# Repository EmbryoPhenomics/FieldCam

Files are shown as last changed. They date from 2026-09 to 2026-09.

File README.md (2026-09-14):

# FieldCam

## A submersible field camera and sensor instrument

FieldCam is a versatile, waterproof imaging and sensing instrument, powered by consumer AA batteries and capable of long term timelapse imaging out in the field.

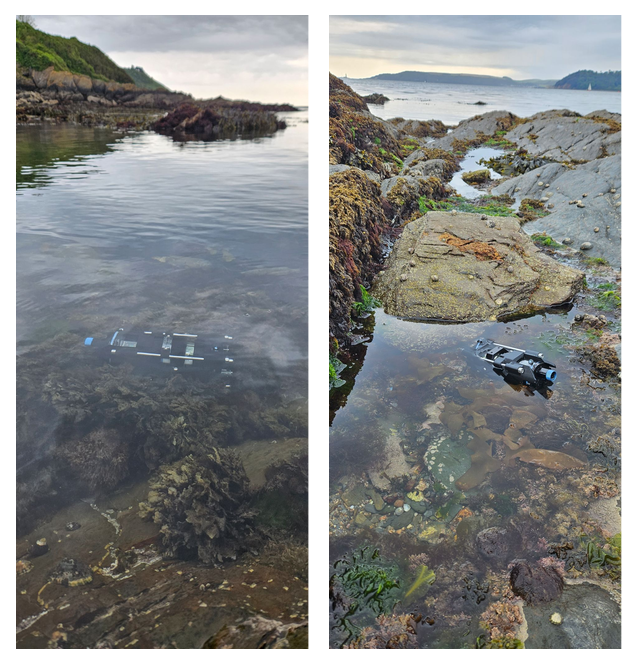
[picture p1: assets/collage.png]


 Some of the key specifications of this instrument are as follows:

| Component | Description |
|:---|:---|
| Waterproof enclosure | Acrylic tube with aluminium end caps rated to 130m depth |
| Battery | 17.1 Ah AA battery pack (~24 hrs continuous video recording). Capacity for additional 22.8 Ah AA battery pack (~30 hrs). Low power mode is > 10 years with continuous system and sensor monitoring (5 second resolution) |
| Processors | STM32 L4 microcontroller for system control and low power standby. Raspberry Pi Zero 2W for video and image capture, 32gb and 1Tb SD cards for storage respectively |
| Camera sensor | CMOS 12-megapixel (Sony IMX708) |
| Video resolution | 1080p50fps maximum. Resolution and framerate can be configured using built-in app |
| Focus | Phase Detection Autofocus (PDAF) or manual adjustable focus. Range 5cm to > 2m. | 
| Camera parameters | Exposure (Auto or manual), analogue gain and auto-white balance modes can all be configured via Web App |
| Lighting | Built-in adjustable LEDs (x2) with up to 170 lm each |
| Sensors | Temperature and light built-in. Pressure, salinity, pH and O2 available with additional sensor pack | 
| Configuration | Setup via Web App using smartphone or laptop, connected to the instrument’s wifi hotspot. Web App enables live streaming and config of camera sensor, viewing of system status and programming of experimental schedule.  All data, including video and sensor logs can be downloaded via network file sharing when in setup mode | 
| Dimensions | 70 mm x 195 mm |

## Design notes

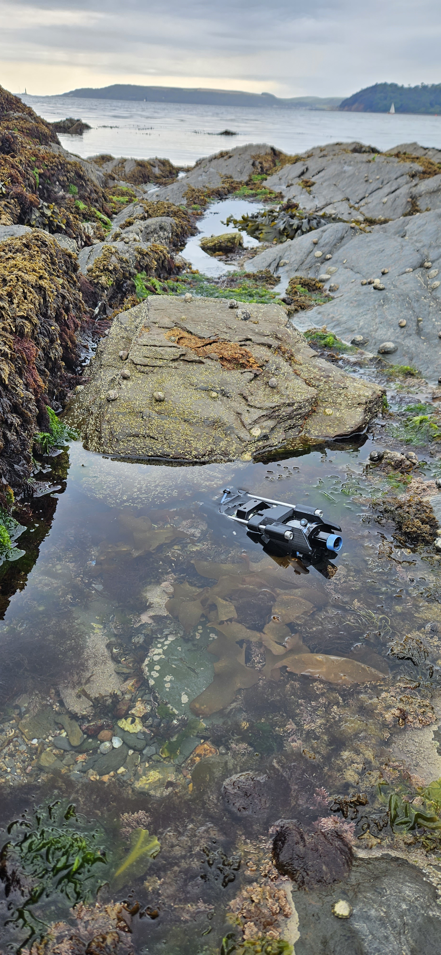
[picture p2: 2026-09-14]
assets/field_img2.jpg

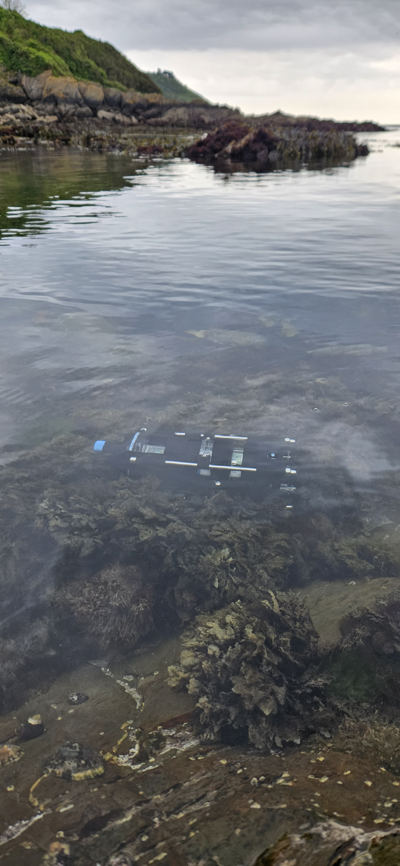
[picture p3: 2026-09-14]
assets/field_img1.jpg

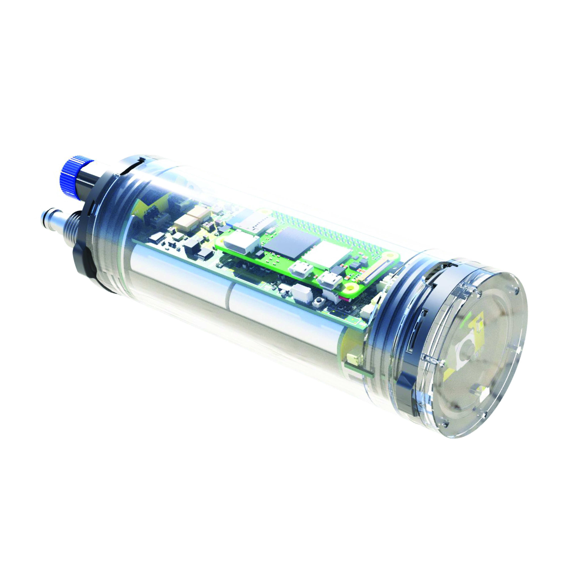
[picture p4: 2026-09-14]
assets/fieldcam_render.jpg

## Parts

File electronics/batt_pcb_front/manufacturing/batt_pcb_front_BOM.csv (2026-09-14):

Reference | Qty | Value | DNP | Exclude from BOM | Exclude from Board | Footprint | Datasheet
BT1 | 1 | Battery_Cell |  |  |  | Battery:BatteryHolder_Keystone_3000_1x12mm | ~
J1 | 1 | Conn_01x02_Socket |  |  |  | Connector_JST:JST_SH_BM02B-SRSS-TB_1x02-1MP_P1.00mm_Vertical | ~
J2,J3,J4,J5,J6,J7 | 6 | Conn_01x01_Pin |  |  |  | jlcpcb:HARWIN_S7091-42R | ~
J8 | 1 | Conn_01x02_Socket |  |  |  | Connector_JST:JST_PH_S2B-PH-SM4-TB_1x02-1MP_P2.00mm_Horizontal | ~

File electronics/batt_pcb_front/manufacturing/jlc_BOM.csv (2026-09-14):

Comment | Designator | Footprint | JLCPCB Part # | Notes | Correct?
Battery_Cell | BT1 | Battery:BatteryHolder_Keystone_3000_1x12mm | C238097 |  | Yes
Conn_01x02_Socket | J1 | Connector_JST:JST_SH_BM02B-SRSS-TB_1x02-1MP_P1.00mm_Vertical | C495537 |  | Yes
Conn_01x01_Pin | J2,J3,J4,J5,J6,J7 | jlcpcb:HARWIN_S7091-42R | C21394879 |  | Yes
Conn_01x02_Socket | J8 | Connector_JST:JST_PH_S2B-PH-SM4-TB_1x02-1MP_P2.00mm_Horizontal | C295747 |  | Yes

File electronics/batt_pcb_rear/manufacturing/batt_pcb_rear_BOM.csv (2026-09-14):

Reference | Qty | Value | DNP | Exclude from BOM | Exclude from Board | Footprint | Datasheet
H1,H2 | 2 | MountingHole |  | Excluded from BOM |  | MountingHole:MountingHole_3.2mm_M3 | ~
H3,H4 | 2 | MountingHole |  | Excluded from BOM |  | MountingHole:MountingHole_2.2mm_M2 | ~
J1,J2,J3,J4,J5,J6 | 6 | Conn_01x01_Pin |  |  |  | jlcpcb:HARWIN_S7091-42R | ~
J8 | 1 | Conn_01x04_Socket |  |  |  | Connector_JST:JST_SH_BM04B-SRSS-TB_1x04-1MP_P1.00mm_Vertical | ~
J9,J10 | 2 | Conn_01x01_Pin |  |  |  | TestPoint:TestPoint_THTPad_4.0x4.0mm_Drill2.0mm | ~
J12,J13 | 2 | Conn_01x03_Socket |  |  |  | jlcpcb:16128981 | ~

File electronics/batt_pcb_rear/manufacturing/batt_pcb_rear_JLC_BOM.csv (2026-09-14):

Comment | Designator | Footprint | JLCPCB Part # | Notes | Correct?
1uF | C1,C5 | Capacitor_SMD:C_0805_2012Metric | C77083
0.1uF | C2,C3,C6,C7 | Capacitor_SMD:C_0603_1608Metric | C77055
1000pF | C4,C8 | Capacitor_SMD:C_0402_1005Metric | C76947
10kR | R1,R2,R3,R4,R5 | Resistor_SMD:R_0603_1608Metric | C99198
TPS22997RYZR | U1,U2 | jlcpcb:WQFN-HR10_RYZ_TEX | C17286840
Conn_01x04_Socket | J8 | Connector_JST:JST_SH_BM04B-SRSS-TB_1x04-1MP_P1.00mm_Vertical | C160390

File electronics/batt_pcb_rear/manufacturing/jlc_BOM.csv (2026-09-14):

Comment | Designator | Footprint | JLCPCB Part # | Notes | Correct?
Conn_01x01_Pin | J1,J2,J3,J4,J5,J6 | jlcpcb:HARWIN_S7091-42R | C21394879
Conn_01x04_Socket | J8 | Connector_JST:JST_SH_BM04B-SRSS-TB_1x04-1MP_P1.00mm_Vertical | C495539

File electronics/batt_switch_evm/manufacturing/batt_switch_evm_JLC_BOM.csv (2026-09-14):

Comment | Designator | Footprint | JLCPCB Part # | Notes | Correct?
INA260 | U3,U1 | TSSOP-16_4.4x5mm_P0.65mm | C2155885
10kR | R3,R5,R4,R2,R1 | R_0603_1608Metric | C99198
1uF | C6 | C_0603_1608Metric | C77386
0.1uF | C4,C1,C9,C15,C12,C14,C5 | C_0603_1608Metric | C77055
100uF | C10,C8,C2 | C_1210_3225Metric | C5719639
10uF | C7,C3,C11 | C_0805_2012Metric | C84416
1000pF | C16 | C_0402_1005Metric | C76947
TPS22997RYZR | U4 | WQFN-HR10_RYZ_TEX | C17286840
1uF | C13 | C_0805_2012Metric | C77083
TPS2117 | U2 | SOT-583-8 | C22399676

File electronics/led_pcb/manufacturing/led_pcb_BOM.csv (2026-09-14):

Reference | Qty | Value | DNP | Exclude from BOM | Exclude from Board | Footprint | Datasheet
C38 | 1 | 100nF |  |  |  | Capacitor_SMD:C_0402_1005Metric | ~
D1,D2 | 2 | LED |  |  |  | jlcpcb:LED-SMD_L3.5-W2.8-R-FD-WHITE | ~
H1,H2 | 2 | MountingHole |  | Excluded from BOM |  | MountingHole:MountingHole_2.2mm_M2 | ~
J1,J2 | 2 | Conn_01x01_Socket |  |  |  | TestPoint:TestPoint_THTPad_2.0x2.0mm_Drill1.0mm | ~
J3,J4 | 2 | Conn_01x04_Socket |  |  |  | Connector_PinHeader_1.27mm:PinHeader_1x04_P1.27mm_Vertical | ~
R32 | 1 | 10kR |  |  |  | Resistor_SMD:R_0402_1005Metric | ~
U10 | 1 | VEML6030 |  |  |  | jlcpcb:VISHAY_VEML6030_2X2X0.87

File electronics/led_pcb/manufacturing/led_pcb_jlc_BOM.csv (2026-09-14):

Comment | Designator | Footprint | JLCPCB Part # | Notes | Correct?
100nF | C38 | Capacitor_SMD:C_0402_1005Metric | C1525
LED | D1,D2 | jlcpcb:LED-SMD_L3.5-W2.8-R-FD-WHITE | C2830573
10kR | R32 | Resistor_SMD:R_0402_1005Metric | C25744
VEML6030 | U10 | jlcpcb:VISHAY_VEML6030_2X2X0.87 | C132182

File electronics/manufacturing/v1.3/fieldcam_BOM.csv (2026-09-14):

Comment | Designator | Footprint | JLCPCB Part # | Notes | Correct?
4.7uF | C1,C51 | Capacitor_SMD:C_0603_1608Metric | C69335
100nF | C2,C3,C4,C7,C36,C37 | Capacitor_SMD:C_0402_1005Metric | C1525
1uF | C5,C22,C27,C33 | Capacitor_SMD:C_0603_1608Metric | C15849
10nF | C6 | Capacitor_SMD:C_0402_1005Metric | C15195
0.1uF | C8,C31 | Capacitor_SMD:C_0402_1005Metric | C307331
10uF | C9 | Capacitor_SMD:C_0603_1608Metric | C19702
15pF | C10,C11 | Capacitor_SMD:C_0402_1005Metric | C441742
0.1uF | C12,C15,C16,C19,C20,C24,C26,C30,C35,C47,C52,C53 | Capacitor_SMD:C_0603_1608Metric | C1591
22uF | C13 | Capacitor_SMD:C_0805_2012Metric | C45783
10uF | C14,C18,C21,C28,C34 | Capacitor_SMD:C_0805_2012Metric | C15850
100uF | C17,C29,C32 | Capacitor_SMD:C_1210_3225Metric | C5719639
1uF | C23,C50 | Capacitor_SMD:C_0805_2012Metric | C28323
2.2uF | C25 | Capacitor_SMD:C_0805_2012Metric | C19110
22uF | C39,C40,C41,C42,C43,C44,C46 | Capacitor_SMD:C_1206_3216Metric | C12891
47uF | C45 | Capacitor_SMD:C_1206_3216Metric | C96123
30pF | C48 | Capacitor_SMD:C_0402_1005Metric | C161152
1000pF | C49,C54 | Capacitor_SMD:C_0402_1005Metric | C76947
Blue LED | D1,D12,D13 | LED_SMD:LED_0603_1608Metric | C5197644
Green LED | D2,D5 | LED_SMD:LED_0603_1608Metric | C3000897
MBRA140T3G | D3 | jlcpcb:SMA_L4.3-W2.6-LS5.2-RD | C54798
MBR120VLSFT1G | D4 | jlcpcb:MBR120VLSFT1G | C223608
Yellow LED | D8,D9 | LED_SMD:LED_0603_1608Metric | C125095
Conn_02x20_Odd_Even | J1 | jlcpcb:CONN-SMD_FH-00369_2x40 | C2685115
Micro_SD_Card_Det2 | J2 | Connector_Card:microSD_HC_Molex_104031-0811 | C585350
Conn_01x02_Socket | J4 | Connector_JST:JST_SH_SM02B-SRSS-TB_1x02-1MP_P1.00mm_Horizontal | C160402
Conn_01x05_Pin | J5 | Connector_JST:JST_SH_BM05B-SRSS-TB_1x05-1MP_P1.00mm_Vertical | C265092
Conn_01x04_Socket | J6 | Connector_JST:JST_SH_SM04B-SRSS-TB_1x04-1MP_P1.00mm_Horizontal | C160404
Conn_01x02_Socket | J8 | Connector_JST:JST_PH_S2B-PH-K_1x02_P2.00mm_Horizontal | C173752
3.3uH | L1,L3 | Inductor_SMD:L_Coilcraft_XAL4030-XXX | C2937437
33uH | L4 | Inductor_SMD:L_Bourns_SRP7028A_7.3x6.6mm | C2046760
2.2uH | L5 | Inductor_SMD:L_Coilcraft_XAL6060-XXX | C3911671
DMP3013SFV | Q3 | Package_SON:Diodes_PowerDI3333-8 | C264098
BSS138 | Q4 | Package_TO_SOT_SMD:SOT-23 | C82045
10kR | R1,R3,R6,R7 | Resistor_SMD:R_0402_1005Metric | C25744
10kR | R2,R4,R5 | Resistor_SMD:R_0402_1005Metric | C25744
1kR | R8,R11,R13,R38,R40 | Resistor_SMD:R_0603_1608Metric | C21190
1.5kR | R12 | Resistor_SMD:R_0603_1608Metric | C22843
10kR | R15,R19,R26,R27,R28,R29,R30,R31,R37,R39 | Resistor_SMD:R_0603_1608Metric | C25804
1R | R16,R18 | Resistor_SMD:R_1206_3216Metric | C513714
3.3kR | R17 | Resistor_SMD:R_0603_1608Metric | C22978
20kR | R20 | Resistor_SMD:R_0603_1608Metric | C4184
7.6kR | R21 | Resistor_SMD:R_0603_1608Metric | C25804
1.15MR | R22 | Resistor_SMD:R_0603_1608Metric | C910920
100kR | R23,R25 | Resistor_SMD:R_0603_1608Metric | C25803
470R | R24 | Resistor_SMD:R_0603_1608Metric | C23179
105kR | R41 | Resistor_SMD:R_0402_1005Metric | C226742
14kR | R42 | Resistor_SMD:R_0402_1005Metric | C284333
36.5kR | R43 | Resistor_SMD:R_0402_1005Metric | C15011
SW_Push | SW1 | jlcpcb:SW-SMD_L3.9-W3.0-P4.45 | C720477
SW_SPDT | SW2 | jlcpcb:SW-SMD_MSK12CO2 | C5149840
SW_Reed | SW3,SW4 | jlcpcb:SENSOR-SMD_59170-1-S-00-D | C315909
STM32L431CCTx | U1 | Package_QFP:LQFP-48_7x7mm_P0.5mm | C486681
INA260 | U2,U4,U5,U11 | Package_SO:TSSOP-16_4.4x5mm_P0.65mm | C2155885
TPS61291DRVT | U3 | jlcpcb:TPS61291 | C464809
TLV61048DBVR | U6 | jlcpcb:SOT-23-6_L2.9-W1.6-P0.95-LS2.8-BR | C2861467
DS3502U_T_R | U7 | jlcpcb:SOP50P490X110-10N | C2649363
AL8860WT | U8 | Package_TO_SOT_SMD:TSOT-23-5 | C125330
TPS2117 | U9 | Package_TO_SOT_SMD:SOT-583-8 | C3235557
TPS61288RQQR | U12 | jlcpcb:TPS61288_VQFN-HR-11_L3.0-W2.5-P0.50-TL | C7498841
TPS22997RYZR | U13 | jlcpcb:WQFN-HR10_RYZ_TEX | C17286840
Crystal | Y1 | jlcpcb:FC-135R_L3.2-W1.5 | C32346

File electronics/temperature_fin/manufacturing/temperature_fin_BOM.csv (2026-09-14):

Reference | Qty | Value | DNP | Exclude from BOM | Exclude from Board | Footprint | Datasheet
C1,C2 | 2 | 1uF |  |  |  | Capacitor_SMD:C_0402_1005Metric | ~
C3 | 1 | 0.1uF |  |  |  | Capacitor_SMD:C_0402_1005Metric | ~
J1 | 1 | Conn_01x04_Socket |  |  |  | Connector_JST:JST_SH_SM04B-SRSS-TB_1x04-1MP_P1.00mm_Horizontal | ~
U1 | 1 | TMP117xxDRV |  |  |  | Package_SON:WSON-6-1EP_2x2mm_P0.65mm_EP1x1.6mm | https://www.ti.com/lit/ds/symlink/tmp117.pdf
U2 | 1 | TPS7A0228PDQNR |  |  |  | jlcpcb:IC_TPS7A0228PDQNR

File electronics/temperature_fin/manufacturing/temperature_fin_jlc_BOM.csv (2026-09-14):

Comment | Designator | Footprint | JLCPCB Part # | Notes | Correct?
1uF | C1,C2 | Capacitor_SMD:C_0402_1005Metric | C52923 |  | Yes
0.1uF | C3 | Capacitor_SMD:C_0402_1005Metric | C307331 |  | Yes
Conn_01x04_Socket | J1 | Connector_JST:JST_SH_SM04B-SRSS-TB_1x04-1MP_P1.00mm_Horizontal | C160404 |  | Yes
TMP117xxDRV | U1 | Package_SON:WSON-6-1EP_2x2mm_P0.65mm_EP1x1.6mm | C699536 |  | Yes
TPS7A0228PDQNR | U2 | jlcpcb:IC_TPS7A0228PDQNR | C5220175 |  | Yes

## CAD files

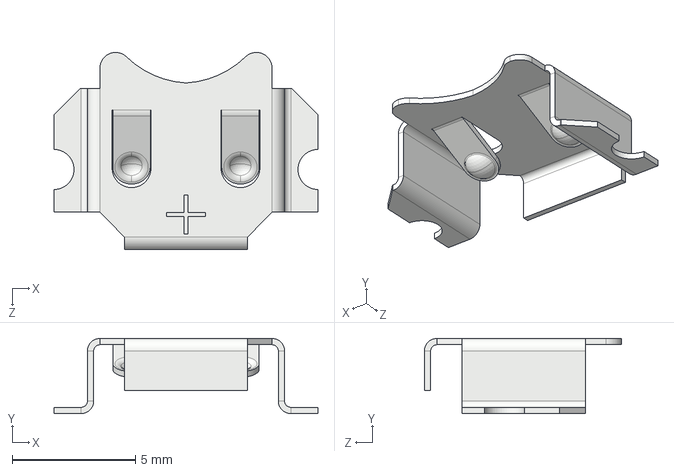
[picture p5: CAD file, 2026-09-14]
electronics/2998(1)/2998.step
10.7 x 3.05 x 8.00 mm

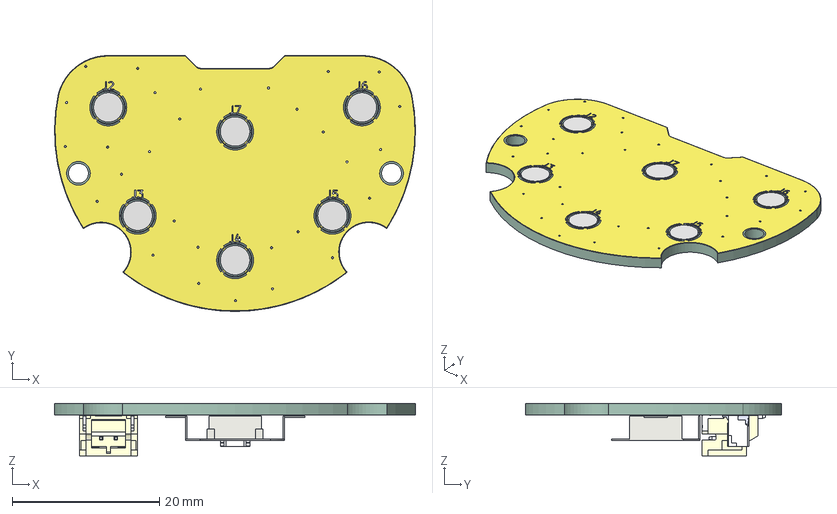
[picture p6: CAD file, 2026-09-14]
electronics/3d_models/batt_pcb_front_v2.step
49.0 x 34.7 x 7.17 mm
S2B-PH-SM4-TB
BMxxB-SRSS-TB(LF)(SN)_02
BatteryHolder_Keystone_3000_1x12mm
batt_pcb_front_copper
batt_pcb_front_pad
batt_pcb_front_via
batt_pcb_front_silkscreen x 2
batt_pcb_front_PCB

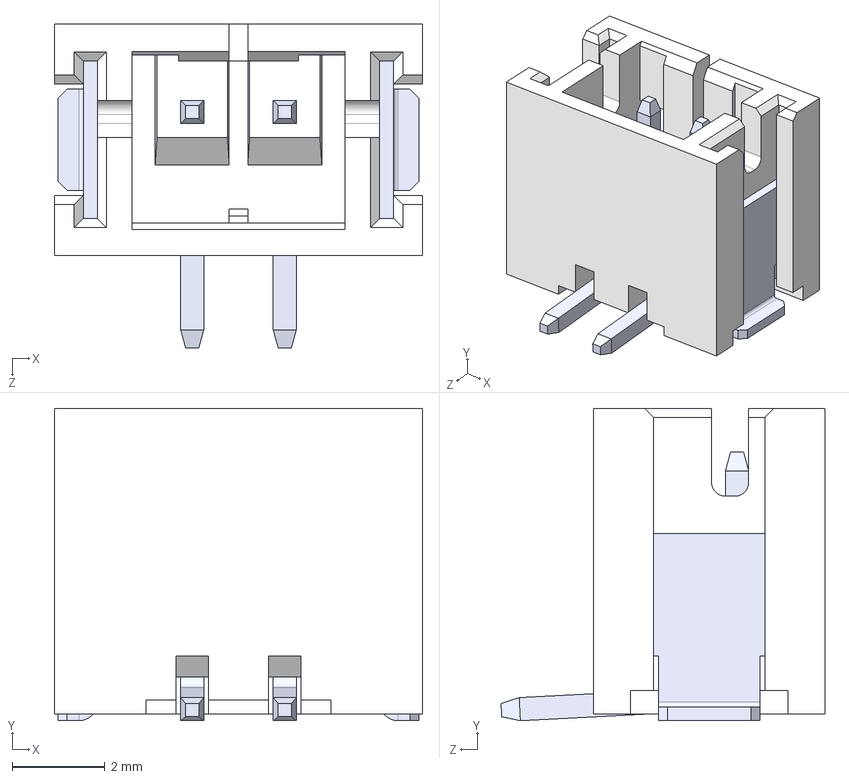
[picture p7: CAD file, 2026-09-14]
electronics/B2B_PH_SM4_TBT/B2B-PH-SM4-TBT.STEP
7.95 x 6.75 x 7.00 mm
BxB-PH-SM4 body_2
BxB-PH-SM4 tab x 2
BxB-PH-SM4 pin x 2

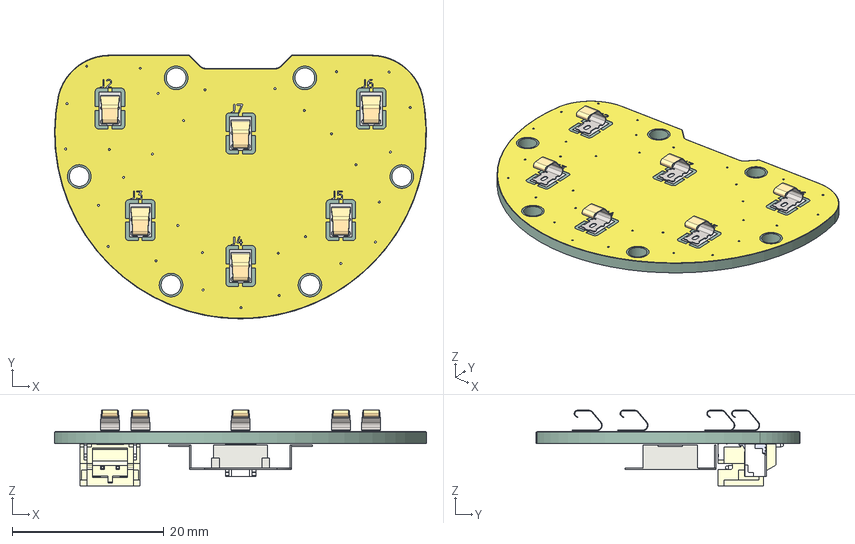
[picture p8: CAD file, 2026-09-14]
electronics/batt_pcb_front/batt_pcb_front.step
49.0 x 34.7 x 9.96 mm
s7091-42r x 6
S2B-PH-SM4-TB
BMxxB-SRSS-TB(LF)(SN)_02
BatteryHolder_Keystone_3000_1x12mm
batt_pcb_front_copper
batt_pcb_front_pad
batt_pcb_front_via
batt_pcb_front_silkscreen
batt_pcb_front_PCB

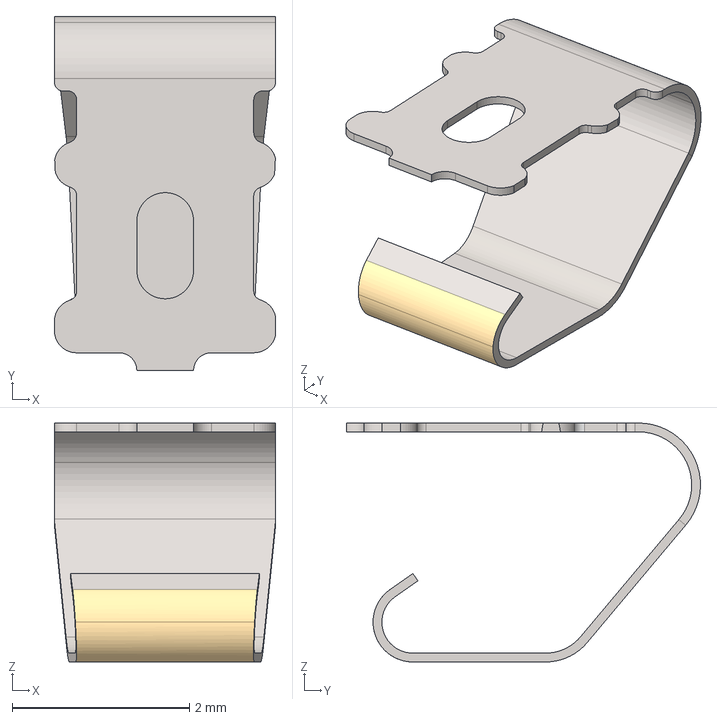
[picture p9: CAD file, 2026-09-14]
electronics/batt_pcb_front/S7091_42R/s7091-42r.stp
2.50 x 4.00 x 2.70 mm

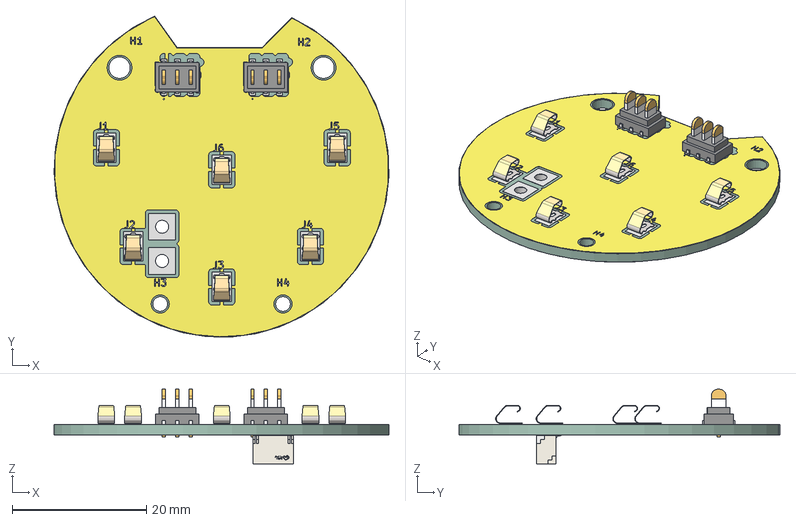
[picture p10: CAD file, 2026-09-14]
electronics/batt_pcb_rear/batt_pcb_rear_BLADE.step
49.9 x 47.8 x 11.1 mm
s7091-42r x 6
CONN-SMD_4P-L6.0-W2.9-H4.3-P1.0
batt_pcb_rear_copper
batt_pcb_rear_pad
batt_pcb_rear_silkscreen
batt_pcb_rear_PCB

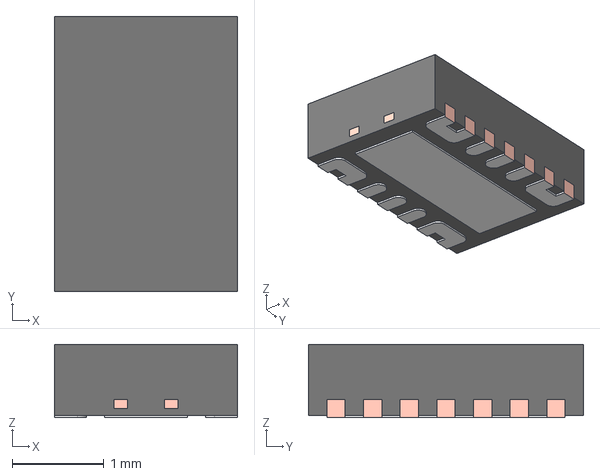
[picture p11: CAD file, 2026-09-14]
electronics/batt_switch_evm/TPS22976DPUR/DPU0014A.stp
2.00 x 3.00 x 0.8 mm
FRAME

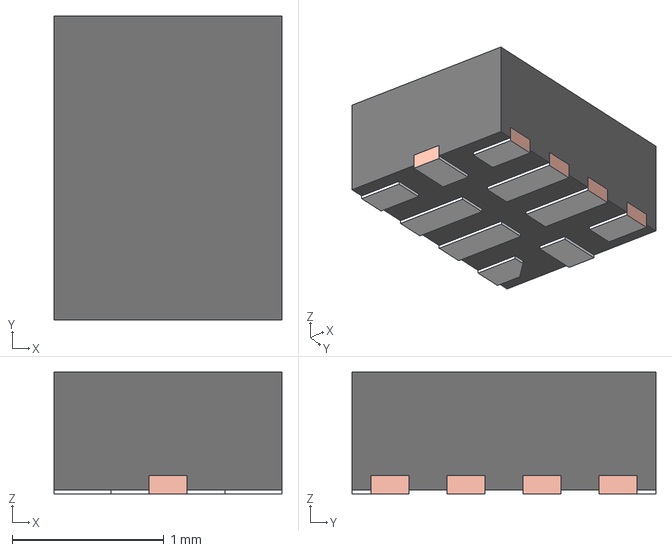
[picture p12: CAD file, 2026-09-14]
electronics/batt_switch_evm/TPS22997RYZR/RYZ0010A.stp
1.50 x 2.00 x 0.8 mm
FRAME-RYZ0010A
BODY-QFN

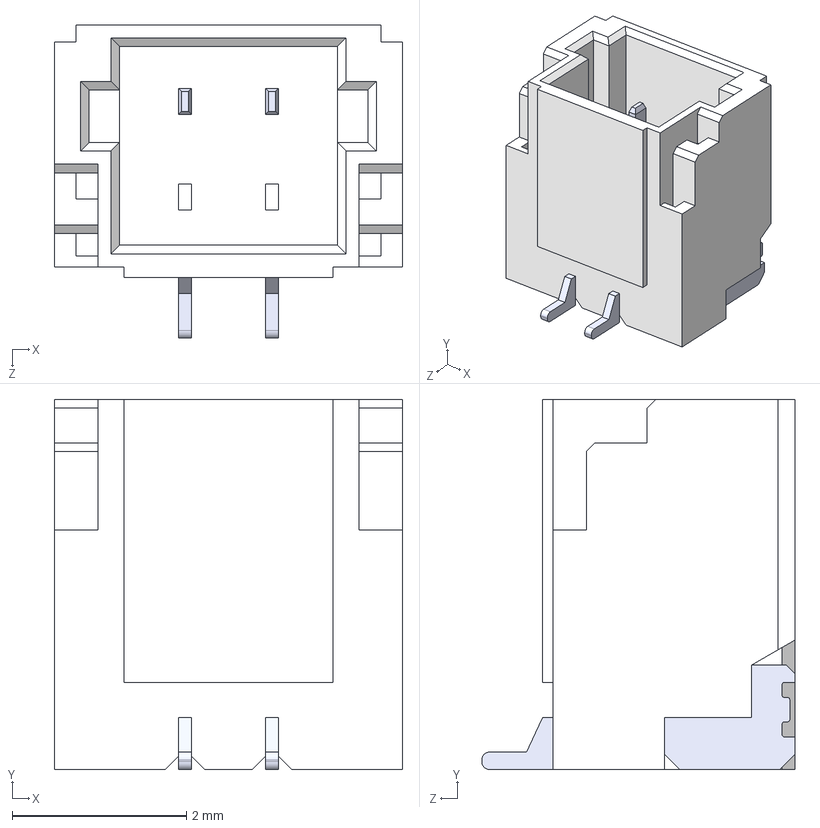
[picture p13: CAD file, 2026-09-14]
electronics/BM02B_SRSS_TB/BM02B-SRSS-TB.STEP
4.00 x 4.25 x 3.60 mm

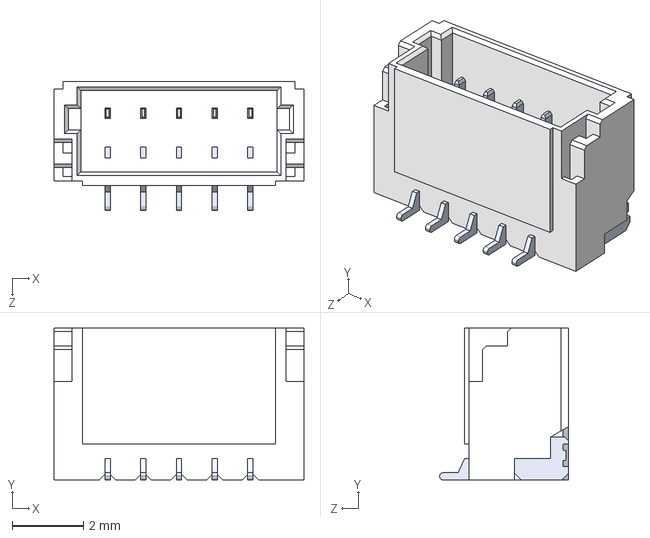
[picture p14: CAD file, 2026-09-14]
electronics/BM05B_SRSS_TB/BM05B-SRSS-TB.STEP
7.00 x 4.25 x 3.60 mm

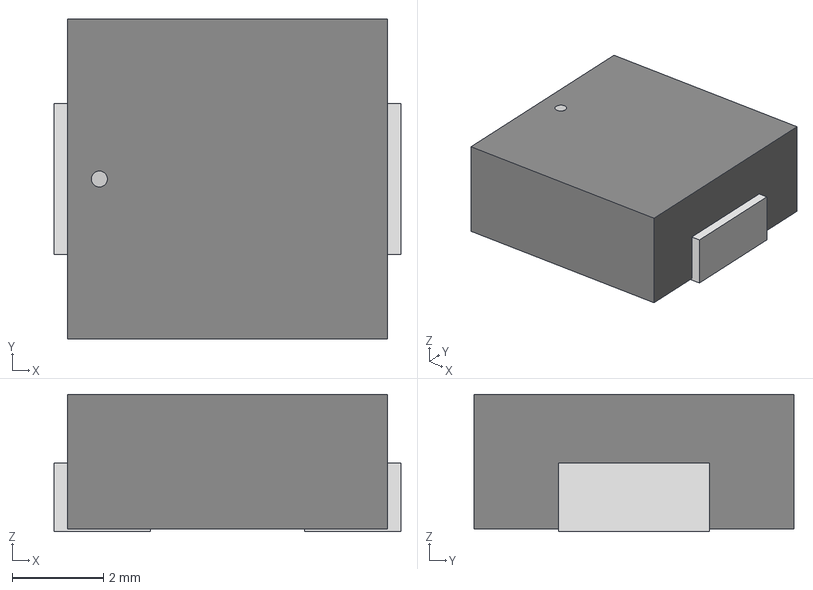
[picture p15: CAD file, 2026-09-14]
electronics/Bourns_SRP7028A/SRP7028A_330M/IND_SRP7028_BRN.step
7.59 x 7.01 x 3.00 mm

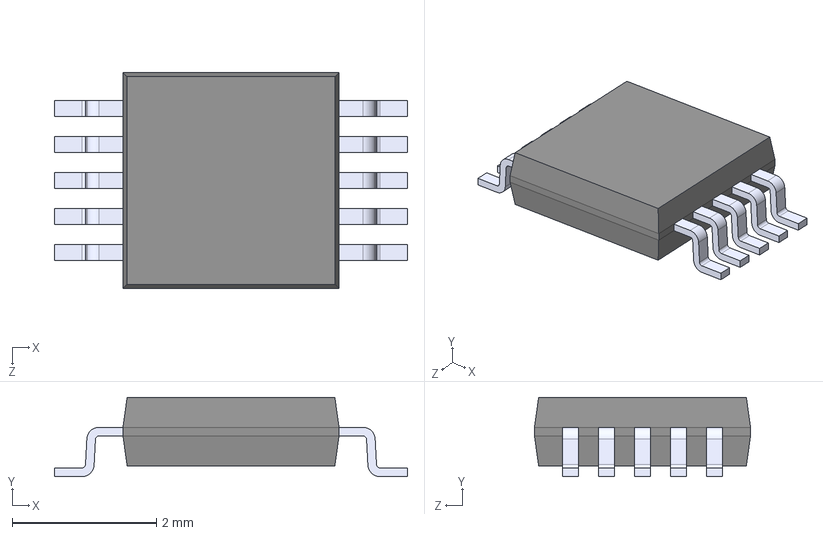
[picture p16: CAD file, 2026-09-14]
electronics/DS3502U_T_R(1)/DS3502U_T_R.step
4.90 x 1.10 x 3.00 mm

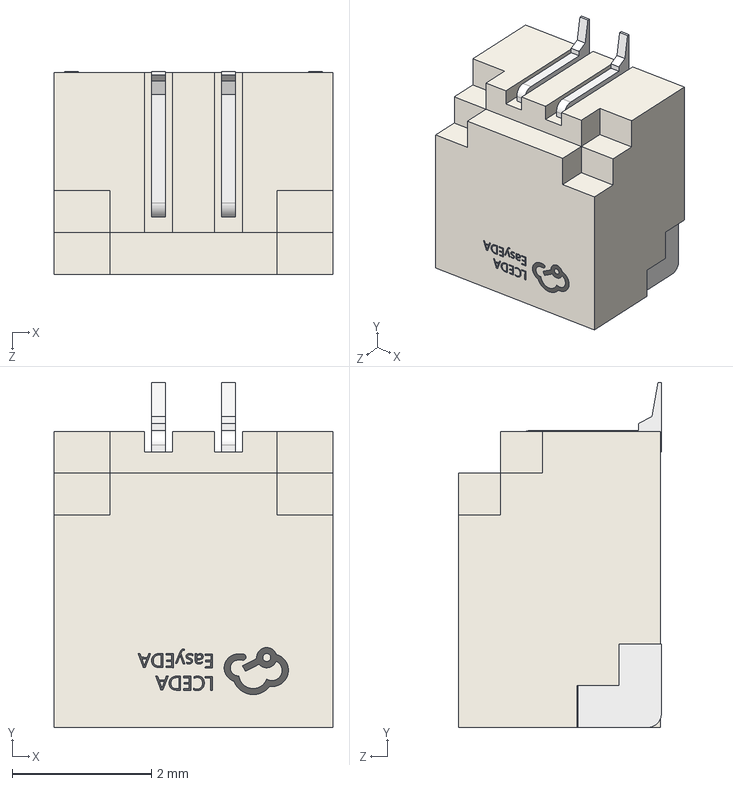
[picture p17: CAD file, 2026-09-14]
electronics/JST_SH_2P/JST_SH_2P_HORIZONTAL.3dshapes_C160402/CONN-SMD_SR1.00-WS-2P.step
4.00 x 4.95 x 2.91 mm

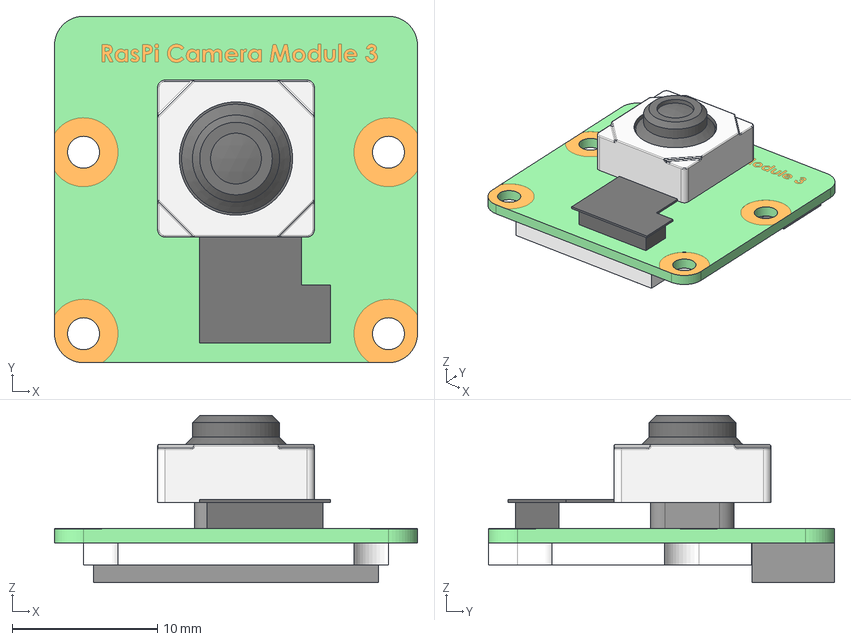
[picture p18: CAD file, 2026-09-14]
electronics/led_pcb/RPI-CAM-3 v1.step
25.0 x 23.9 x 11.5 mm

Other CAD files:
electronics/LM66200DRLR/DRL0008A.stp
electronics/LM8364BALMF20_NOPB(1)/LM8364BALMF20.step
electronics/RPI_GPIO_CONN/RPI-ZERO-2 v10.step
electronics/S2B_PH_SM4_TB/S2B-PH-SM4-TB.STEP
electronics/1612898-1/3D/1612898-1.stp
electronics/1612898-1/Allegro/16128981.psm
electronics/1612898-1/DEHDL/1612898_1/chips/chips.prt
electronics/1612901-1/3D/1612901-1.stp
electronics/1612901-1/Allegro/16129011.psm
electronics/1612901-1/DEHDL/1612901_1/chips/chips.prt
electronics/1827654-1/3D/1827654-1.stp
electronics/1827654-1/Allegro/18276541.psm
electronics/1827654-1/DEHDL/1827654_1/chips/chips.prt
electronics/3d_models/batt_pcb_rear_v2.step
electronics/3d_models/led_pcb_v2.step
electronics/5787526-1/3D/5787526-1.stp
electronics/5787526-1/Allegro/57875261.psm
electronics/5787526-1/DEHDL/5787526_1/chips/chips.prt
electronics/6318977-3/3D/6318977-3.stp
electronics/6318977-3/Allegro/63189773.psm
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

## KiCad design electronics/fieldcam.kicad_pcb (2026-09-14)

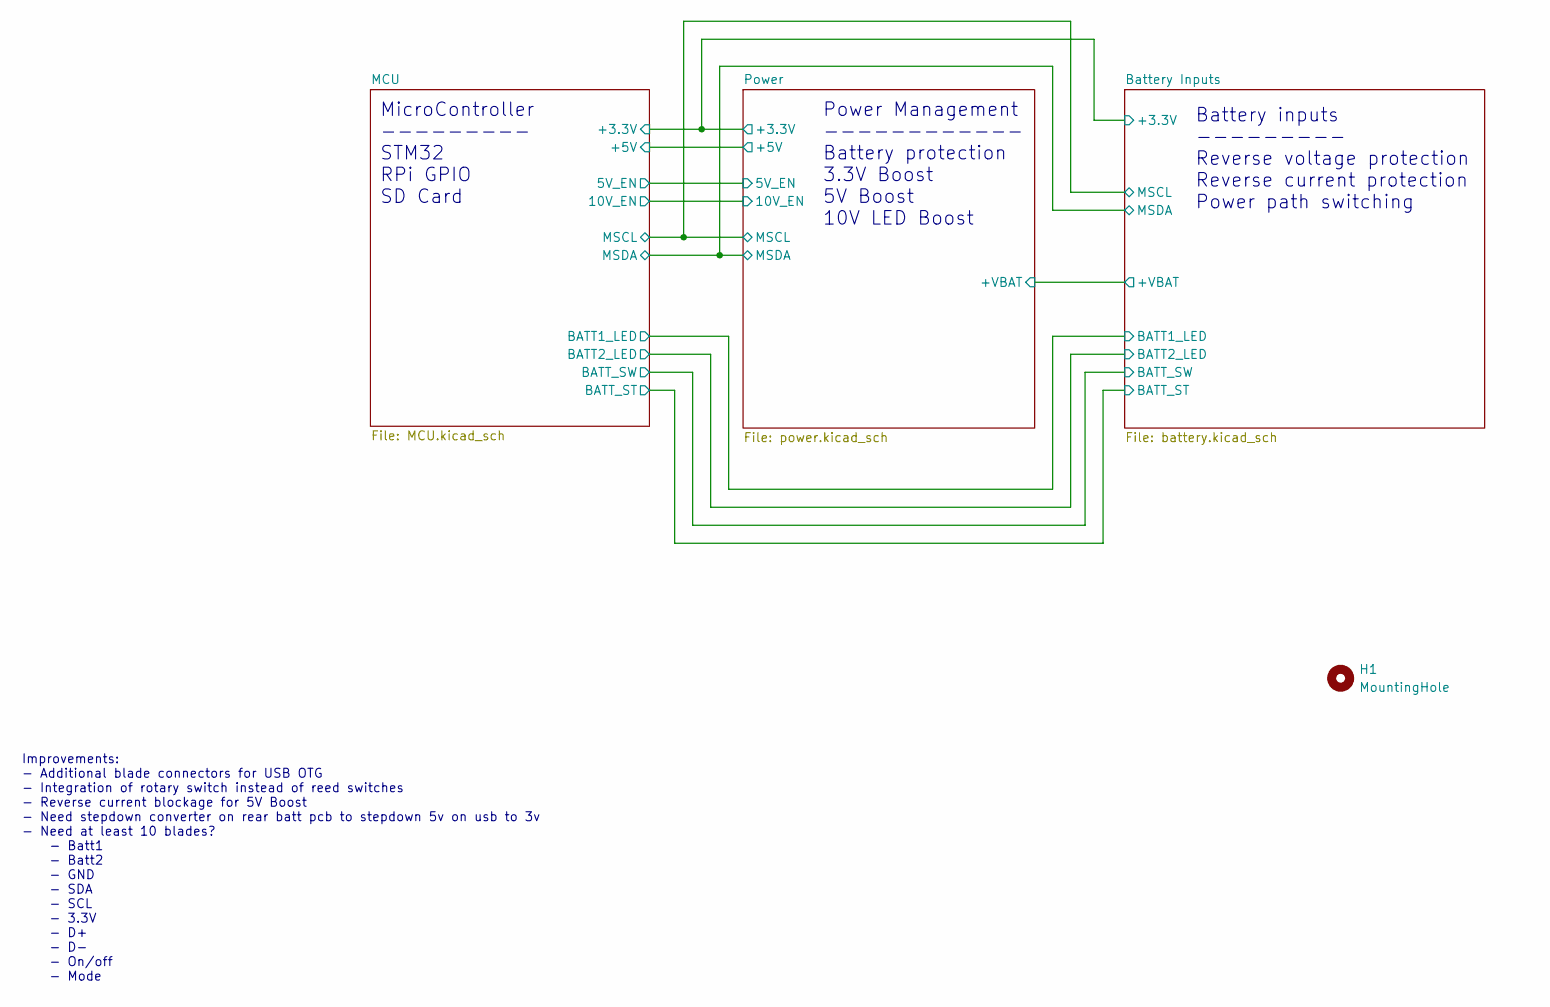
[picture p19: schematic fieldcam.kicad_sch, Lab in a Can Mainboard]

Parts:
H1: MountingHole; MountingHole_2.7mm_M2.5

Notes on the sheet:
Improvements: - Additional blade connectors for USB OTG - Integration of rotary switch instead of reed switches - Reverse current blockage for 5V Boost - Need stepdown converter on rear batt pcb to stepdown 5v on usb to 3v - Need at least 10 blades? - Batt1 - Batt2 - GND - SDA - SCL - 3.3V - D+ - D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
Power Management ------------ Battery protection 3.3V Boost 5V Boost 10V LED Boost
Battery inputs --------- Reverse voltage protection Reverse current protection Power path switching
MicroController --------- STM32 RPi GPIO SD Card

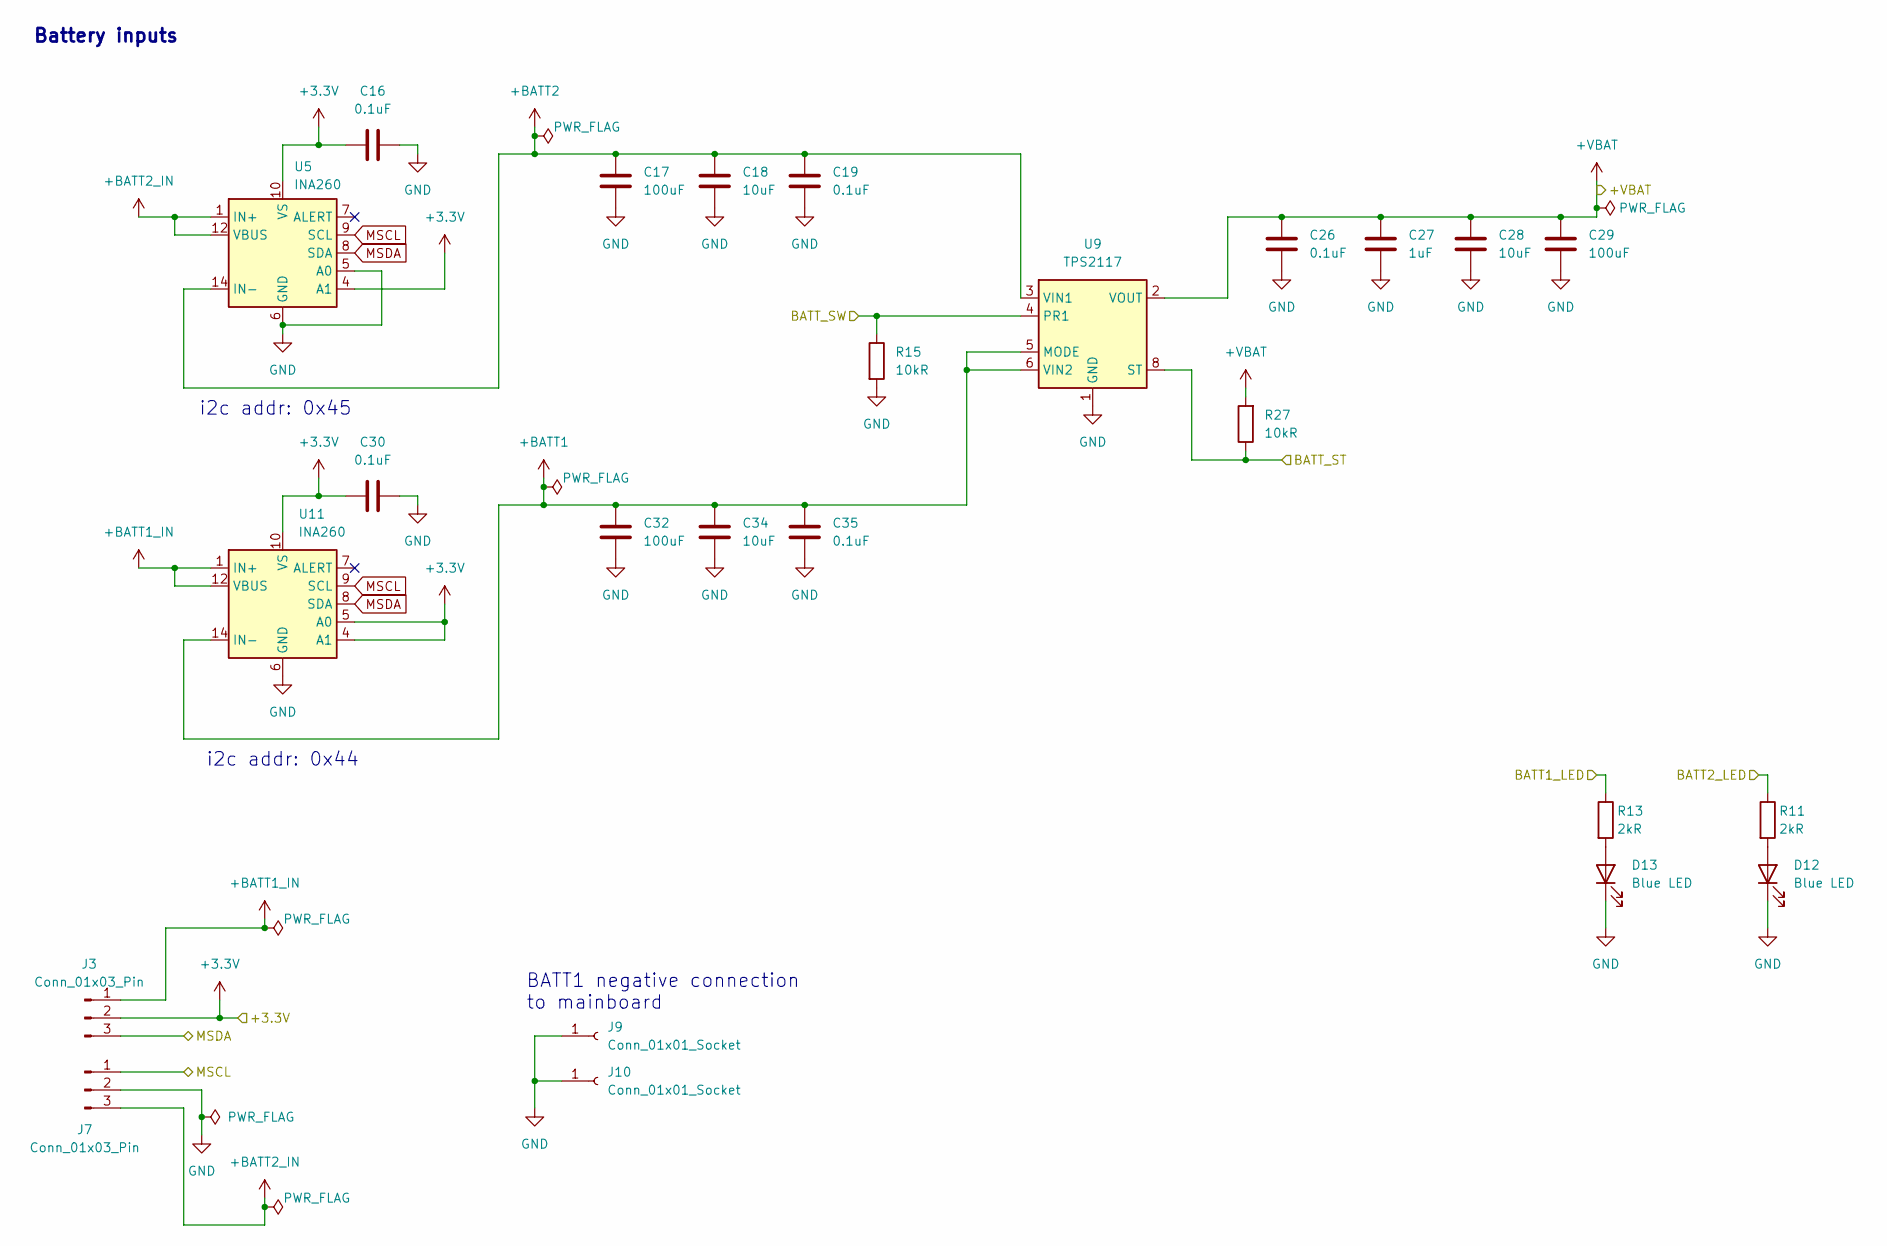
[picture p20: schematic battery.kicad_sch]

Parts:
C16, C19, C26, C30, C35: 0.1uF; C_0603_1608Metric
C17, C29, C32: 100uF; C_1210_3225Metric
C18, C28, C34: 10uF; C_0805_2012Metric
C27: 1uF; C_0603_1608Metric
D12, D13: Blue LED; LED_0603_1608Metric
J3, J7: Conn_01x03_Pin; 16129011
J9, J10: Conn_01x01_Socket; TestPoint_Pad_2.0x2.0mm
R11, R13: 2kR; R_0603_1608Metric
R15, R27: 10kR; R_0603_1608Metric
U5, U11: INA260; TSSOP-16_4.4x5mm_P0.65mm
U9: TPS2117; SOT-583-8

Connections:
+3.3V: C16.1, C30.1, J3.2, U5.4 (A1), U5.10 (VS), U11.4 (A1), U11.5 (A0), U11.10 (VS); also elsewhere on the board
+BATT1: C32.1, C34.1, C35.1, U9.5 (MODE), U9.6 (VIN2), U11.14 (IN-), U11.15 (IN-), U11.16 (IN-)
+BATT1_IN: J3.1, U11.1 (IN+), U11.2 (IN+), U11.3 (IN+), U11.12 (VBUS)
+BATT2: C17.1, C18.1, C19.1, U5.14 (IN-), U5.15 (IN-), U5.16 (IN-), U9.3 (VIN1)
+BATT2_IN: J7.3, U5.1 (IN+), U5.2 (IN+), U5.3 (IN+), U5.12 (VBUS)
+VBAT: C26.1, C27.1, C28.1, C29.1, R27.2, U9.2 (VOUT), U9.7 (VOUT); also elsewhere on the board
/Battery Inputs/BATT1_LED: R13.1; also elsewhere on the board
/Battery Inputs/BATT2_LED: R11.1; also elsewhere on the board
/Battery Inputs/BATT_ST: R27.1, U9.8 (ST); also elsewhere on the board
/Battery Inputs/BATT_SW: R15.1, U9.4 (PR1); also elsewhere on the board
GND: C16.2, C17.2, C18.2, C19.2, C26.2, C27.2, C28.2, C29.2, C30.2, C32.2, C34.2, C35.2, D12.1 (K), D13.1 (K), J7.2, J9.1 (Pin_1_1), J10.1 (Pin_1_1), R15.2, U5.5 (A0), U5.6 (GND), U5.11 (GND), U9.1 (GND), U11.6 (GND), U11.11 (GND); also elsewhere on the board
MSCL: J7.1, U5.9 (SCL), U11.9 (SCL); also elsewhere on the board
MSDA: J3.3, U5.8 (SDA), U11.8 (SDA); also elsewhere on the board
unnamed: D12.2 (A), R11.2
unnamed: D13.2 (A), R13.2

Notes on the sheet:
i2c addr: 0x45
BATT1 negative connection to mainboard
Battery inputs
i2c addr: 0x44

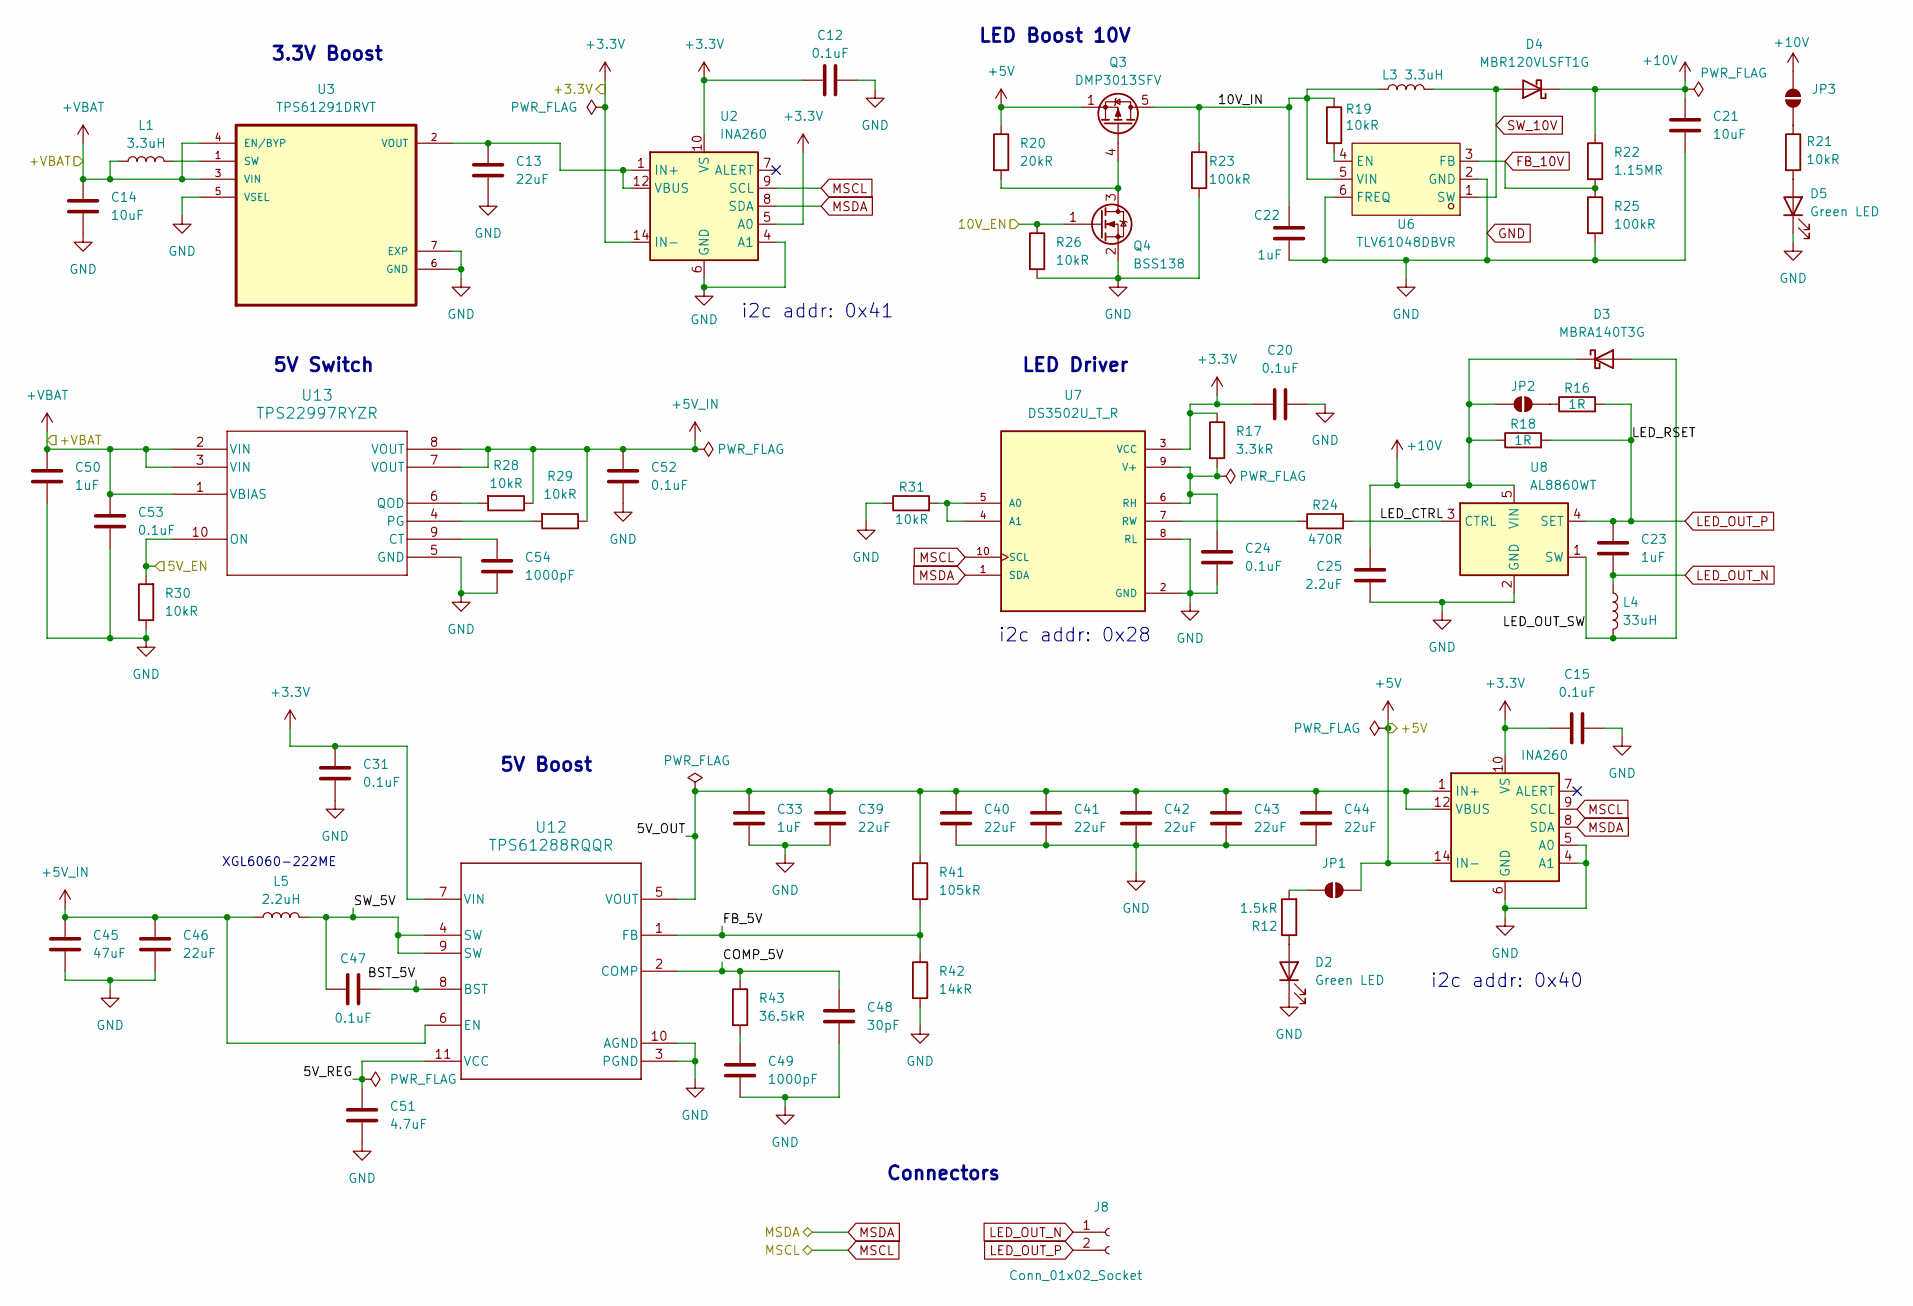
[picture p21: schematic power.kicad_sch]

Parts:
C12, C15, C20, C24, C47, C52, C53: 0.1uF; C_0603_1608Metric
C13: 22uF; C_0805_2012Metric
C14, C21: 10uF; C_0805_2012Metric
C22, C33: 1uF; C_0603_1608Metric
C23, C50: 1uF; C_0805_2012Metric
C25: 2.2uF; C_0805_2012Metric
C31: 0.1uF; C_0402_1005Metric
C39, C40, C41, C42, C43, C44, C46: 22uF; C_1206_3216Metric
C45: 47uF; C_1206_3216Metric
C48: 30pF; C_0402_1005Metric
C49, C54: 1000pF; C_0402_1005Metric
C51: 4.7uF; C_0603_1608Metric
D2, D5: Green LED; LED_0603_1608Metric
D3: MBRA140T3G; SMA_L4.3-W2.6-LS5.2-RD
D4: MBR120VLSFT1G
J8: Conn_01x02_Socket; JST_PH_S2B-PH-K_1x02_P2.00mm_Horizontal
JP1, JP2, JP3: SolderJumper_2_Open; SolderJumper-2_P1.3mm_Open_Pad1.0x1.5mm
L1, L3: 3.3uH; L_Coilcraft_XAL4030-XXX
L4: 33uH; L_Bourns_SRP7028A_7.3x6.6mm
L5: 2.2uH; L_Coilcraft_XAL6060-XXX
Q3: DMP3013SFV; Diodes_PowerDI3333-8
Q4: BSS138; SOT-23
R12: 1.5kR; R_0603_1608Metric
R16, R18: 1R; R_1206_3216Metric
R17: 3.3kR; R_0603_1608Metric
R19, R21, R26, R28, R29, R30, R31: 10kR; R_0603_1608Metric
R20: 20kR; R_0603_1608Metric
R22: 1.15MR; R_0603_1608Metric
R23, R25: 100kR; R_0603_1608Metric
R24: 470R; R_0603_1608Metric
R41: 105kR; R_0402_1005Metric
R42: 14kR; R_0402_1005Metric
R43: 36.5kR; R_0402_1005Metric
U2, U4: INA260; TSSOP-16_4.4x5mm_P0.65mm
U3: TPS61291DRVT; TPS61291
U6: TLV61048DBVR; SOT-23-6_L2.9-W1.6-P0.95-LS2.8-BR; LCSC Part C2861467
U7: DS3502U_T_R; SOP50P490X110-10N; PARTREV 23/05/19
U8: AL8860WT; TSOT-23-5
U12: TPS61288RQQR; TPS61288_VQFN-HR-11_L3.0-W2.5-P0.50-TL
U13: TPS22997RYZR; WQFN-HR10_RYZ_TEX

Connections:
+3.3V: C12.1, C15.1, C20.1, C31.1, R17.1, U2.5 (A0), U2.10 (VS), U2.14 (IN-), U2.15 (IN-), U2.16 (IN-), U4.10 (VS), U7.3 (VCC), U12.7 (VIN); also elsewhere on the board
+5V: JP1.1 (A), Q3.1 (S), Q3.2 (S), Q3.3 (S), R20.1, U4.14 (IN-), U4.15 (IN-), U4.16 (IN-); also elsewhere on the board
+5V_IN: C45.1, C46.1, C52.1, L5.1, R28.1, R29.1, U12.6 (EN), U13.7 (VOUT), U13.8 (VOUT)
+10V: C21.1, C25.1, D3.1 (K), D4.1 (K), JP2.2 (B), JP3.2 (B), R18.1, R22.1, U8.5 (VIN)
+VBAT: C14.1, C50.1, C53.1, L1.1, U3.3 (VIN), U3.4 (EN/BYP), U13.1 (VBIAS), U13.2 (VIN), U13.3 (VIN); also elsewhere on the board
/MCU/5V_EN: R30.2, U13.10 (ON); also elsewhere on the board
/MCU/10V_EN: Q4.1 (G), R26.1; also elsewhere on the board
/Power/5V_OUT: C33.1, C39.1, C40.1, C41.1, C42.1, C43.1, C44.1, R41.1, U4.1 (IN+), U4.2 (IN+), U4.3 (IN+), U4.12 (VBUS), U12.5 (VOUT)
/Power/5V_REG: C51.1, U12.11 (VCC)
/Power/10V_IN: C22.1, L3.1, Q3.5 (D), R19.1, R23.1, U6.5 (VIN)
/Power/BST_5V: C47.2, U12.8 (BST)
/Power/COMP_5V: C48.1, R43.1, U12.2 (COMP)
/Power/FB_5V: R41.2, R42.1, U12.1 (FB)
/Power/LED_CTRL: R24.2, U8.3 (CTRL)
/Power/LED_OUT_SW: D3.2 (A), L4.2, U8.1 (SW)
/Power/SW_5V: C47.1, L5.2, U12.4 (SW), U12.9 (SW)
FB_10V: R22.2, R25.1, U6.3 (FB)
GND: C12.2, C13.2, C14.2, C15.2, C20.2, C21.2, C22.2, C24.1, C25.2, C31.2, C33.2, C39.2, C40.2, C41.2, C42.2, C43.2, C44.2, C45.2, C46.2, C48.2, C49.2, C50.2, C51.2, C52.2, C53.2, C54.2, D2.1 (K), D5.1 (K), Q4.2 (S), R23.2, R25.2, R26.2, R30.1, R31.1, R42.2, U2.4 (A1), U2.6 (GND), U2.11 (GND), U3.5 (VSEL), U3.6 (GND), U3.7 (EXP), U4.4 (A1), U4.5 (A0), U4.6 (GND), U4.11 (GND), U6.2 (GND), U6.6 (FREQ), U7.2 (GND), U7.8 (RL), U8.2 (GND), U12.3 (PGND), U12.10 (AGND), U13.5 (GND); also elsewhere on the board
LED_OUT_N: C23.2, J8.1, L4.1
LED_OUT_P: C23.1, J8.2, R16.2, R18.2, U8.4 (SET)
MSCL: U2.9 (SCL), U4.9 (SCL), U7.10 (SCL); also elsewhere on the board
MSDA: U2.8 (SDA), U4.8 (SDA), U7.1 (SDA); also elsewhere on the board
unnamed: C49.1, R43.2
unnamed: D2.2 (A), R12.1
unnamed: D5.2 (A), R21.2
unnamed: JP1.2 (B), R12.2
unnamed: JP2.1 (A), R16.1
unnamed: JP3.1 (A), R21.1
unnamed: Q3.4 (G), Q4.3 (D), R20.2
unnamed: C13.1, U2.1 (IN+), U2.2 (IN+), U2.3 (IN+), U2.12 (VBUS), U3.2 (VOUT)
unnamed: L1.2, U3.1 (SW)
unnamed: R19.2, U6.4 (EN)
unnamed: R31.2, U7.4 (A1), U7.5 (A0)
unnamed: C24.2, R17.2, U7.6 (RH), U7.9 (V+)
unnamed: R24.1, U7.7 (RW)
unnamed: C54.1, U13.9 (CT)
unnamed: R29.2, U13.4 (PG)
unnamed: R28.2, U13.6 (QOD)
SW_10V: D4.2 (A), L3.2, U6.1 (SW)

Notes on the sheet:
5V Switch
i2c addr: 0x28
i2c addr: 0x41
LED Driver
LED Boost 10V
i2c addr: 0x40
XGL6060-222ME
Connectors
3.3V Boost
5V Boost

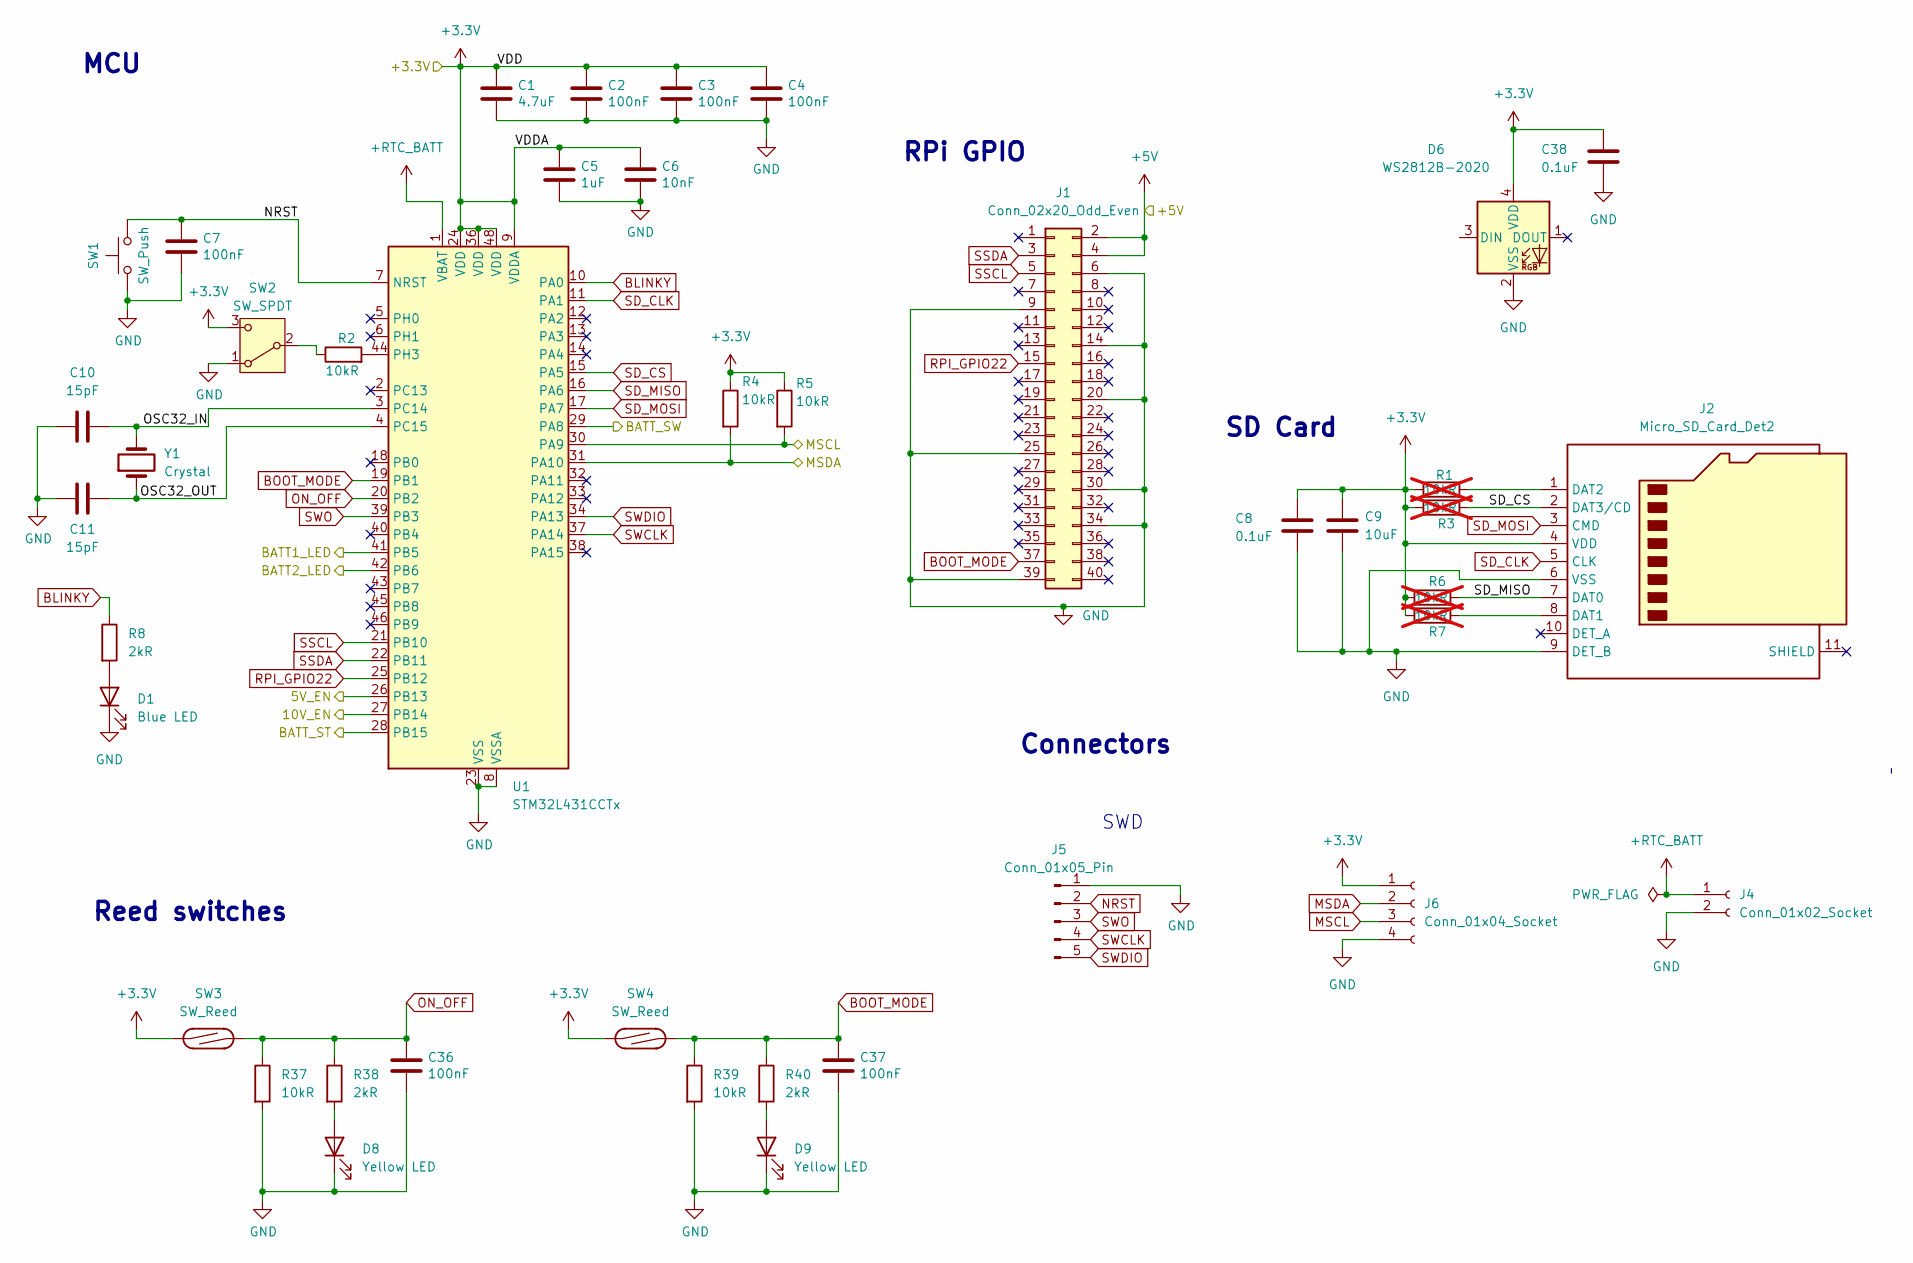
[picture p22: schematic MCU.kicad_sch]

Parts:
C1: 4.7uF; C_0603_1608Metric
C2, C3, C4, C7, C36, C37: 100nF; C_0402_1005Metric
C5: 1uF; C_0603_1608Metric
C6: 10nF; C_0402_1005Metric
C8, C38: 0.1uF; C_0402_1005Metric
C9: 10uF; C_0603_1608Metric
C10, C11: 15pF; C_0402_1005Metric
D1: Blue LED; LED_0603_1608Metric
D6: WS2812B-2020; LED_WS2812B-2020_PLCC4_2.0x2.0mm
D8, D9: Yellow LED; LED_0603_1608Metric
J1: Conn_02x20_Odd_Even; CONN-SMD_FH-00369_2x40
J2: Micro_SD_Card_Det2; microSD_HC_Molex_104031-0811
J4: Conn_01x02_Socket; JST_SH_SM02B-SRSS-TB_1x02-1MP_P1.00mm_Horizontal
J5: Conn_01x05_Pin; JST_SH_BM05B-SRSS-TB_1x05-1MP_P1.00mm_Vertical
J6: Conn_01x04_Socket; JST_SH_SM04B-SRSS-TB_1x04-1MP_P1.00mm_Horizontal
R1, R3, R6, R7: 10kR; R_0402_1005Metric; not fitted
R2, R4, R5: 10kR; R_0402_1005Metric
R8, R38, R40: 2kR; R_0603_1608Metric
R37, R39: 10kR; R_0603_1608Metric
SW1: SW_Push; SW-SMD_L3.9-W3.0-P4.45
SW2: SW_SPDT; SW-SMD_MSK12CO2
SW3, SW4: SW_Reed; SENSOR-SMD_59170-1-S-00-D
U1: STM32L431CCTx; LQFP-48_7x7mm_P0.5mm
Y1: Crystal; FC-135R_L3.2-W1.5

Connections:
+3.3V: C1.1, C2.1, C3.1, C4.1, C5.1, C6.1, C8.1, C9.1, C38.1, D6.4 (VDD), J2.4 (VDD), J6.1, R1.1, R3.1, R4.1, R5.1, R6.1, R7.1, SW2.3 (C), SW3.1, SW4.1, U1.9 (VDDA), U1.24 (VDD), U1.36 (VDD), U1.48 (VDD); also elsewhere on the board
+5V: J1.2, J1.4; also elsewhere on the board
+RTC_BATT: J4.1, U1.1 (VBAT)
/Battery Inputs/BATT1_LED: U1.41 (PB5); also elsewhere on the board
/Battery Inputs/BATT2_LED: U1.42 (PB6); also elsewhere on the board
/Battery Inputs/BATT_ST: U1.28 (PB15); also elsewhere on the board
/Battery Inputs/BATT_SW: U1.29 (PA8); also elsewhere on the board
/MCU/5V_EN: U1.26 (PB13); also elsewhere on the board
/MCU/10V_EN: U1.27 (PB14); also elsewhere on the board
/MCU/OSC32_IN: C10.2, U1.3 (PC14), Y1.2
/MCU/OSC32_OUT: C11.2, U1.4 (PC15), Y1.1
BLINKY: R8.1, U1.10 (PA0)
BOOT_MODE: C37.1, J1.37, R39.1, R40.1, SW4.2, U1.19 (PB1)
GND: C1.2, C2.2, C3.2, C4.2, C5.2, C6.2, C7.2, C8.2, C9.2, C10.1, C11.1, C36.2, C37.2, C38.2, D1.1 (K), D6.2 (VSS), D8.1 (K), D9.1 (K), J1.6, J1.9, J1.14, J1.20, J1.25, J1.30, J1.34, J1.39, J2.6 (VSS), J2.9 (DET_B), J4.2, J5.1, J6.4, R37.2, R39.2, SW1.1, SW2.1 (A), U1.8 (VSSA), U1.23 (VSS), U1.35 (VSS), U1.47 (VSS); also elsewhere on the board
MSCL: J6.3, R5.2, U1.30 (PA9); also elsewhere on the board
MSDA: J6.2, R4.2, U1.31 (PA10); also elsewhere on the board
NRST: C7.1, J5.2, SW1.2, U1.7 (NRST)
unnamed: D1.2 (A), R8.2
unnamed: D8.2 (A), R38.2
unnamed: D9.2 (A), R40.2
unnamed: J2.8 (DAT1), R7.2
unnamed: J2.1 (DAT2), R1.2
unnamed: R2.1, SW2.2 (B)
unnamed: R2.2, U1.44 (PH3)
ON_OFF: C36.1, R37.1, R38.1, SW3.2, U1.20 (PB2)
RPI_GPIO22: J1.15, U1.25 (PB12)
SD_CLK: J2.5 (CLK), U1.11 (PA1)
SD_CS: J2.2 (DAT3/CD), R3.2, U1.15 (PA5)
SD_MISO: J2.7 (DAT0), R6.2, U1.16 (PA6)
SD_MOSI: J2.3 (CMD), U1.17 (PA7)
SSCL: J1.5, U1.21 (PB10)
SSDA: J1.3, U1.22 (PB11)
SWCLK: J5.4, U1.37 (PA14)
SWDIO: J5.5, U1.34 (PA13)
SWO: J5.3, U1.39 (PB3)

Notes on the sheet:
Connectors
SWD
MCU
RPi GPIO
Reed switches
SD Card

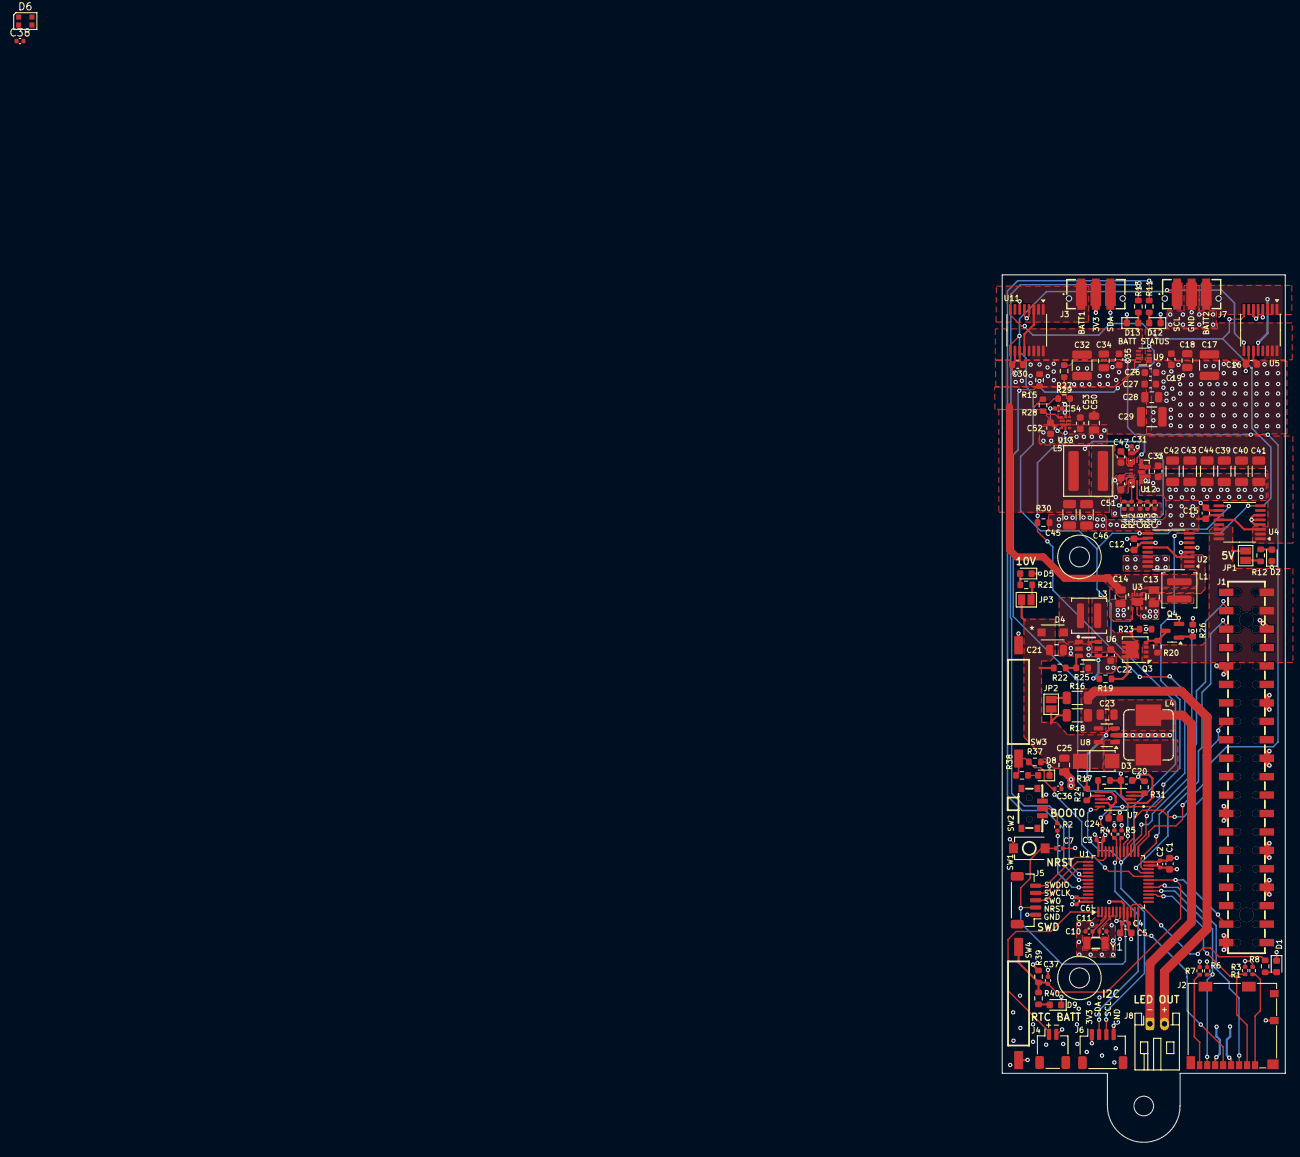
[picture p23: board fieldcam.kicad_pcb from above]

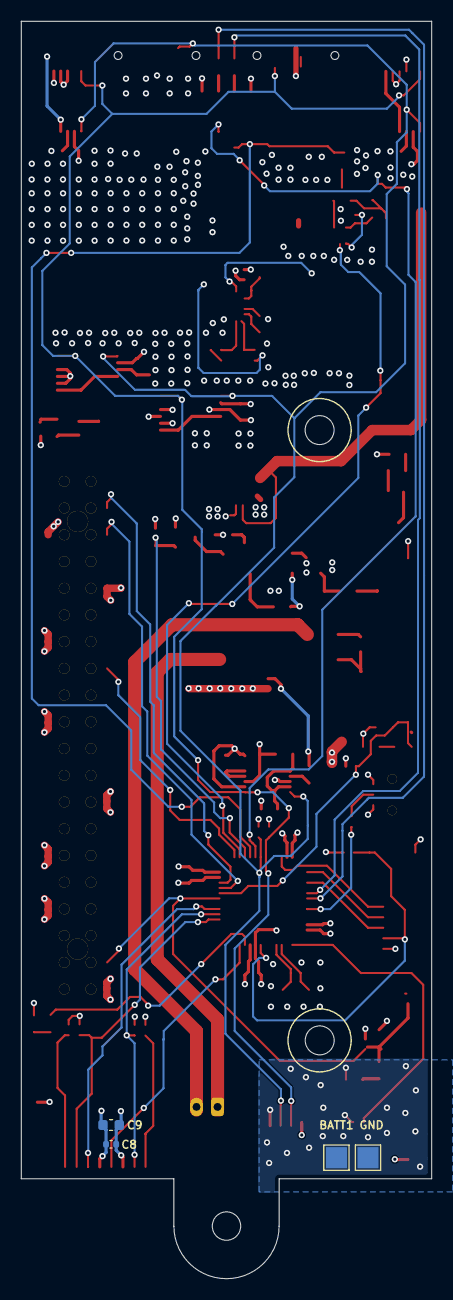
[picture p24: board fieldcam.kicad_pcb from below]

Board: 4 copper layers, 39.0 x 119.5 mm, 136 parts (4 on the bottom side), 73 nets.

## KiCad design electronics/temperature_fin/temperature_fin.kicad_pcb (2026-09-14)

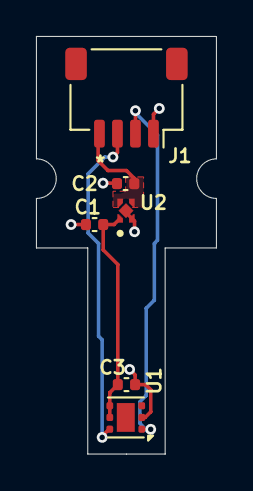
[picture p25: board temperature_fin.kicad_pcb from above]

Board: 2 copper layers, 10.0 x 23.2 mm, 6 parts (0 on the bottom side), 5 nets.

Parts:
C1, C2: 1uF; C_0402_1005Metric
C3: 0.1uF; C_0402_1005Metric
J1: Conn_01x04_Socket; JST_SH_SM04B-SRSS-TB_1x04-1MP_P1.00mm_Horizontal
U1: TMP117xxDRV; WSON-6-1EP_2x2mm_P0.65mm_EP1x1.6mm
U2: TPS7A0228PDQNR; IC_TPS7A0228PDQNR

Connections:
+2V8: C1.1, C3.1, U1.4 (ADD0), U1.5 (V+), U2.1 (OUT)
+3V3: C2.1, J1.4, U2.3 (EN), U2.4 (IN)
GND: C1.2, C2.2, C3.2, J1.1, U1.2 (GND), U2.2 (GND), U2.5 (THERMAL_PAD)
SCL: J1.2, U1.1 (SCL)
SDA: J1.3, U1.6 (SDA)

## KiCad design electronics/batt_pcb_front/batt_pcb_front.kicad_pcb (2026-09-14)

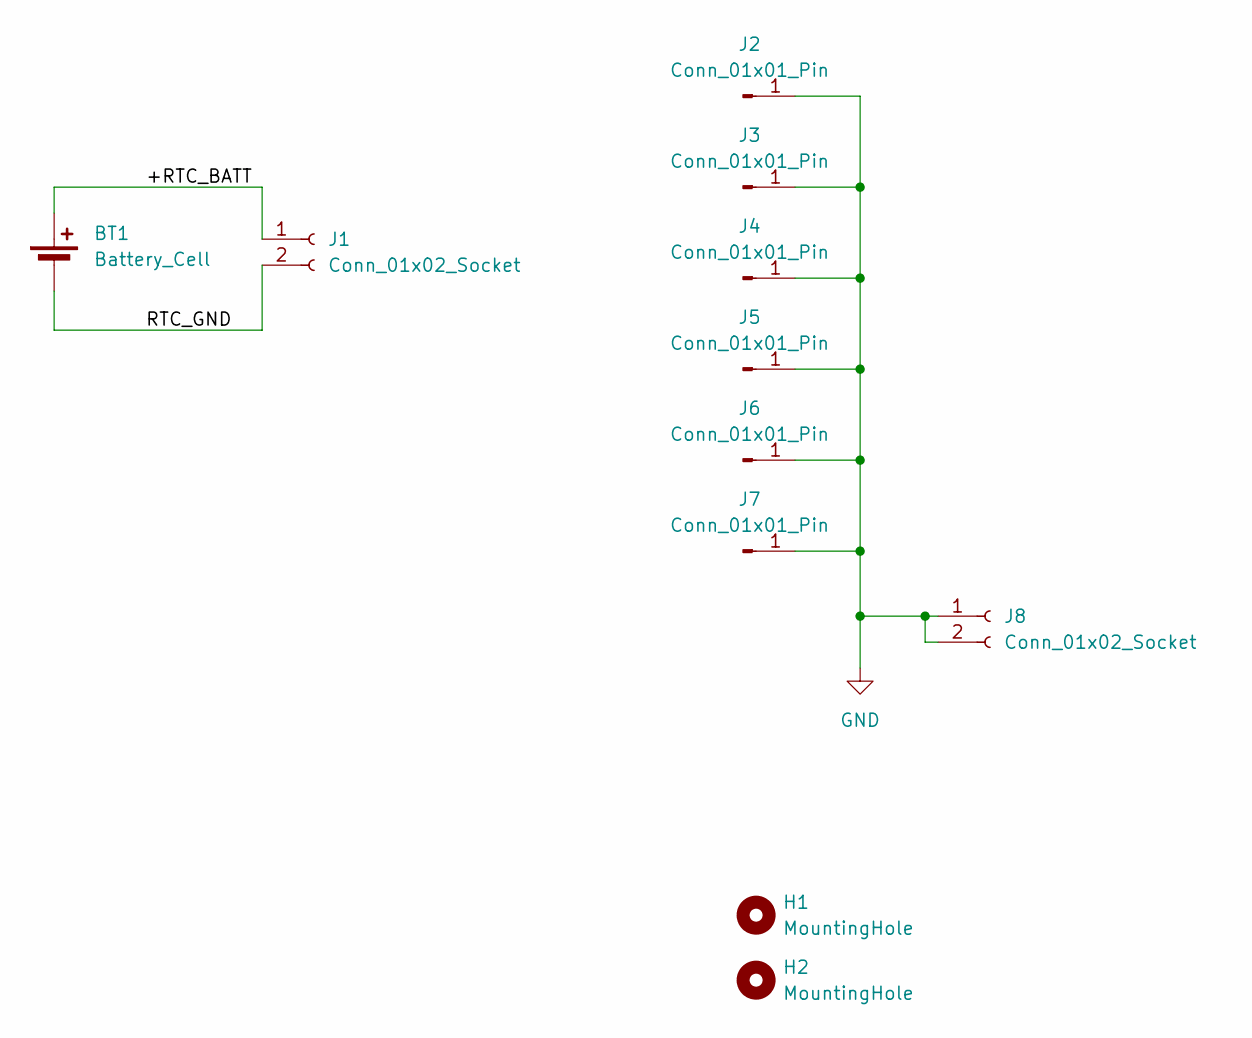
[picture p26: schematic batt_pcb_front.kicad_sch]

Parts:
BT1: Battery_Cell; BatteryHolder_Keystone_3000_1x12mm
H1, H2: MountingHole; MountingHole_2.7mm_M2.5
J1: Conn_01x02_Socket; JST_SH_BM02B-SRSS-TB_1x02-1MP_P1.00mm_Vertical
J2, J3, J4, J5, J6, J7: Conn_01x01_Pin; TestPoint_Pad_D4.0mm
J8: Conn_01x02_Socket; JST_PH_S2B-PH-SM4-TB_1x02-1MP_P2.00mm_Horizontal

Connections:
/+RTC_BATT: BT1.1 (+), J1.1
/RTC_GND: BT1.2 (-), J1.2
GND: J2.1, J3.1, J4.1, J5.1, J6.1, J7.1, J8.1, J8.2

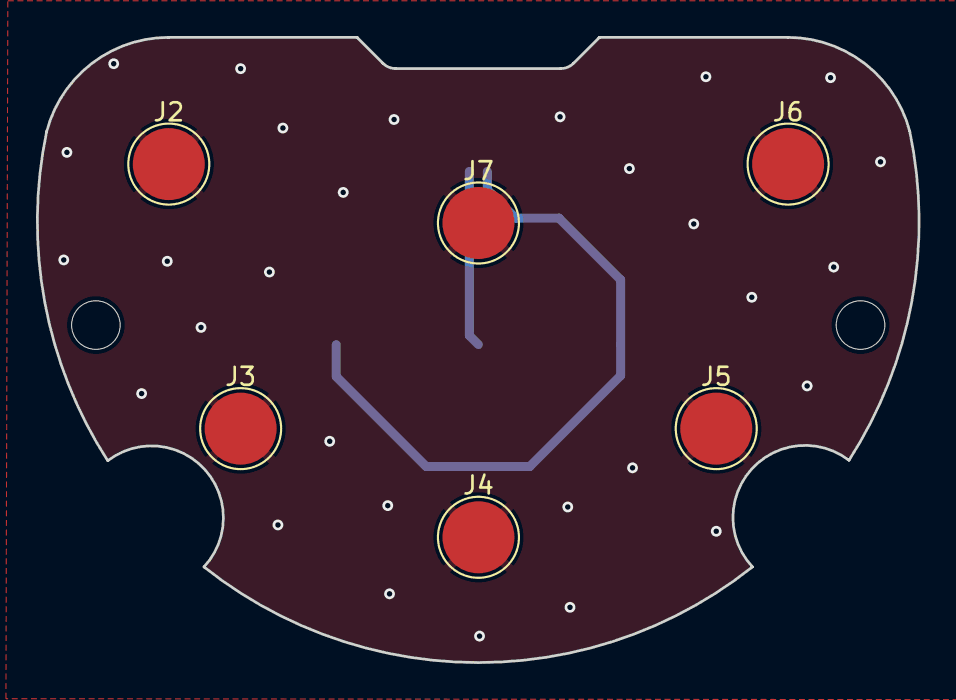
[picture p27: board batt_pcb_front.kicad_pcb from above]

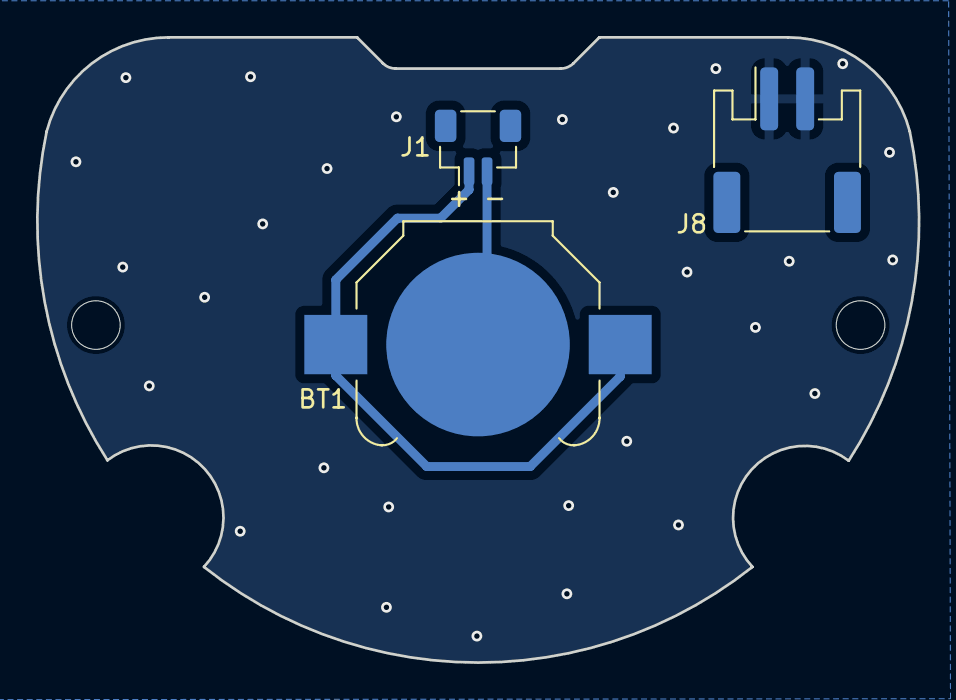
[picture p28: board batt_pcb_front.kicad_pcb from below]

Board: 2 copper layers, 49.0 x 34.7 mm, 11 parts (3 on the bottom side), 3 nets.

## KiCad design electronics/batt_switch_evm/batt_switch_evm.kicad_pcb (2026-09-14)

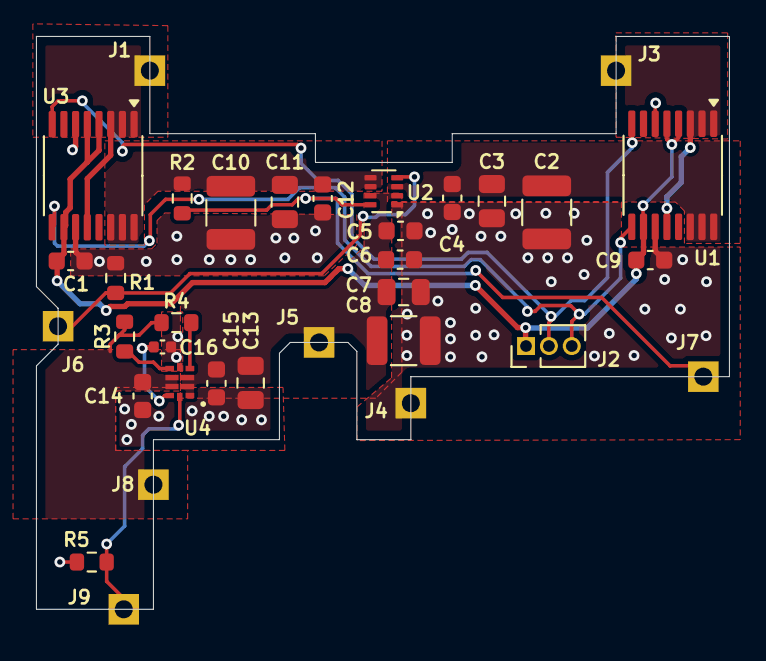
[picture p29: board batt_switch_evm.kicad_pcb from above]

Board: 2 copper layers, 38.5 x 31.8 mm, 34 parts (0 on the bottom side), 16 nets.

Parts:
C1, C4, C5, C9, C12, C14, C15: 0.1uF; C_0603_1608Metric
C2, C8, C10: 100uF; C_1210_3225Metric
C3, C7, C11: 10uF; C_0805_2012Metric
C6: 1uF; C_0603_1608Metric
C13: 1uF; C_0805_2012Metric
C16: 1000pF; C_0402_1005Metric
J1, J3, J4, J5, J6, J7, J8, J9: Conn_01x01_Pin; PinSocket_1x01_P2.54mm_Vertical
J2: Conn_01x03_Socket; PinHeader_1x03_P1.27mm_Vertical
R1, R2, R3, R4, R5: 10kR; R_0603_1608Metric
U1, U3: INA260; TSSOP-16_4.4x5mm_P0.65mm
U2: TPS2117; SOT-583-8
U4: TPS22997RYZR; WQFN-HR10_RYZ_TEX

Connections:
5V_EN: J9.1, R5.2, U4.10 (ON)
+3.3V: C1.1, C9.1, J2.1, U1.4 (A1), U1.5 (A0), U1.10 (VS), U3.4 (A1), U3.5 (A0), U3.10 (VS)
+5V_IN: C14.1, J8.1, R3.1, R4.1, U4.7 (VOUT), U4.8 (VOUT)
+BATT1: C10.1, C11.1, C12.1, R2.2, U2.5 (MODE), U2.6 (VIN2), U3.14 (IN-), U3.15 (IN-), U3.16 (IN-)
+BATT2: C2.1, C3.1, C4.1, U1.14 (IN-), U1.15 (IN-), U1.16 (IN-), U2.3 (VIN1)
+VBAT: C5.1, C6.1, C7.1, C8.1, C13.1, C15.1, J5.1, U2.2 (VOUT), U2.7 (VOUT), U4.1 (VBIAS), U4.2 (VIN), U4.3 (VIN)
BATT1_IN: J1.1, U3.1 (IN+), U3.2 (IN+), U3.3 (IN+), U3.12 (VBUS)
BATT2_IN: J3.1, U1.1 (IN+), U1.2 (IN+), U1.3 (IN+), U1.12 (VBUS)
BATT_ST: J7.1, R2.1, U2.8 (ST)
BATT_SW: J6.1, R1.1, U2.4 (PR1)
GND: C1.2, C2.2, C3.2, C4.2, C5.2, C6.2, C7.2, C8.2, C9.2, C10.2, C11.2, C12.2, C13.2, C14.2, C15.2, C16.2, J4.1, R1.2, R5.1, U1.6 (GND), U1.11 (GND), U2.1 (GND), U3.6 (GND), U3.11 (GND), U4.5 (GND)
MSCL: J2.3, U1.9 (SCL), U3.9 (SCL)
MSDA: J2.2, U1.8 (SDA), U3.8 (SDA)
unnamed: C16.1, U4.9 (CT)
unnamed: R4.2, U4.4 (PG)
unnamed: R3.2, U4.6 (QOD)

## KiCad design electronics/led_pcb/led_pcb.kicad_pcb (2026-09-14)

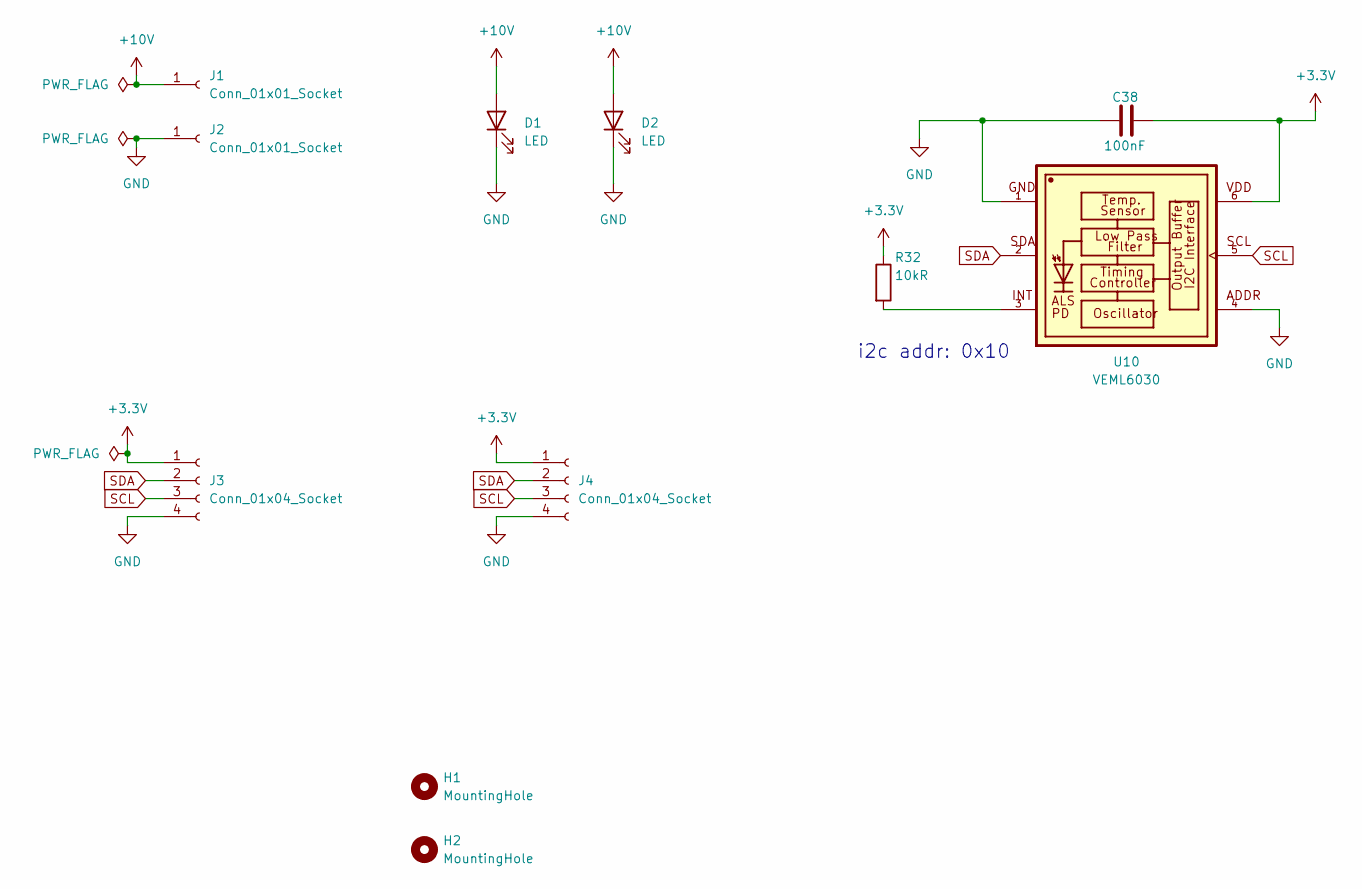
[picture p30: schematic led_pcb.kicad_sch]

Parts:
C38: 100nF; C_0402_1005Metric
D1, D2: LED; LED-SMD_L3.5-W2.8-R-FD-WHITE
H1, H2: MountingHole; MountingHole_2.2mm_M2
J1, J2: Conn_01x01_Socket; TestPoint_THTPad_2.0x2.0mm_Drill1.0mm
J3, J4: Conn_01x04_Socket; PinHeader_1x04_P1.27mm_Vertical
R32: 10kR; R_0402_1005Metric
U10: VEML6030; VISHAY_VEML6030_2X2X0.87

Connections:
+3.3V: C38.2, J3.1, J4.1, R32.1, U10.6
+10V: D1.2 (A), D2.2 (A), J1.1
GND: C38.1, D1.1 (K), D2.1 (K), J2.1, J3.4, J4.4, U10.1, U10.4
MSCL: J3.3, J4.3, U10.5
MSDA: J3.2, J4.2, U10.2
unnamed: R32.2, U10.3

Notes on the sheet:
i2c addr: 0x10



Board: 2 copper layers, 35.1 x 17.6 mm, 11 parts (2 on the bottom side), 6 nets.

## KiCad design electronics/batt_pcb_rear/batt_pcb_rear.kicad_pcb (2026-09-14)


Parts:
C1, C5: 1uF; C_0805_2012Metric
C2, C3, C6, C7: 0.1uF; C_0603_1608Metric
C4, C8: 1000pF; C_0402_1005Metric
J1, J2, J3, J4, J5, J6: Conn_01x01_Pin; TestPoint_Pad_D2.5mm
J7, J11: Conn_01x01_Socket; SolderWire-1sqmm_1x01_D1.4mm_OD2.7mm
J8: Conn_01x04_Socket; JST_SH_BM04B-SRSS-TB_1x04-1MP_P1.00mm_Vertical
J9, J10: Conn_01x01_Pin; TestPoint_THTPad_4.0x4.0mm_Drill2.0mm
J12, J13: Conn_01x03_Socket; 16128981
R1, R2, R3, R4, R5: 10kR; R_0603_1608Metric
U1, U2: TPS22997RYZR; WQFN-HR10_RYZ_TEX

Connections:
+3.3V: J8.1, J12.2
+BATT1: C2.1, J12.1, R1.1, R2.1, U1.7 (VOUT), U1.8 (VOUT)
+BATT1_IN: C1.1, C3.1, J1.1, J2.1, J3.1, J4.1, J5.1, J6.1, J11.1, U1.1 (VBIAS), U1.2 (VIN), U1.3 (VIN)
+BATT2: C6.1, J13.3, R4.1, R5.1, U2.7 (VOUT), U2.8 (VOUT)
+BATT2_IN: C5.1, C7.1, J9.1, U2.1 (VBIAS), U2.2 (VIN), U2.3 (VIN)
GND: C1.2, C2.2, C3.2, C4.2, C5.2, C6.2, C7.2, C8.2, J8.4, J10.1, J13.2, R3.1, U1.5 (GND), U2.5 (GND)
unnamed: C4.1, U1.9 (CT)
unnamed: R2.2, U1.4 (PG)
unnamed: R1.2, U1.6 (QOD)
unnamed: C8.1, U2.9 (CT)
unnamed: R5.2, U2.4 (PG)
unnamed: R4.2, U2.6 (QOD)
PWR_EN: J7.1, R3.2, U1.10 (ON), U2.10 (ON)
SCL: J8.3, J13.1
SDA: J8.2, J12.3



Board: 2 copper layers, 48.0 x 46.1 mm, 32 parts (20 on the bottom side), 15 nets.

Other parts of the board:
UNK_HOLE_0: dummyfp0
UNK_HOLE_1: dummyfp1
UNK_HOLE_2: dummyfp2
UNK_HOLE_3: dummyfp3

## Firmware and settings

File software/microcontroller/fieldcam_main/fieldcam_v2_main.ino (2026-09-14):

#include <Arduino.h> 
#include "STM32LowPower.h"
#include <string>
#include <Wire.h>
#include <Adafruit_INA260.h>
#include <Adafruit_DS3502.h>
#include <SPI.h>
#include <SD.h>
#include <map>
#include <string>
#include <STM32RTC.h>
#include "SparkFun_VEML6030_Ambient_Light_Sensor.h"
#include <SparkFun_TMP117.h> // Used to send and recieve specific information from our sensor

// To do
// Dynamic lighting based on light sensor

// Blinky
#define LED_BUILTIN PA0

// Pin Definitions:
#define SDA1_MASTER PA10
#define SCL1_MASTER PA9

#define SDA2_SLAVE PB11 // Slave to RPi Master
#define SCL2_SLAVE PB10 // Slave to RPi Master

// SD chip select
#define SD_CS PA5

/* Power Control */
#define EN_5V PB13
#define EN_10V PB14
#define BATT_SW PA8
#define BATT_ST PB15

// Battery LEDs
#define BATT1_LED PB5
#define BATT2_LED PB6

// Mode Switches
#define TURN_ON_OFF PB2

#define RPI_GPIO22 PB12

// Definitions of global variables -----
float rpi_volts, rpi_current, rpi_power;
float uc_volts, uc_current, uc_power;
float batt1_volts, batt1_current, batt1_power;
float batt2_volts, batt2_current, batt2_power;
bool POWER_CHECK = false;

float temp_celsius;
long light_lux;

uint8_t led_brightness = 0;

// Wake and sleep parameters set by RPi
uint32_t watchdog_time_config;
volatile uint32_t watchdog_end_time;

uint16_t poweroff_time_config;
volatile uint32_t poweroff_end_time;

// Acquisition config
uint8_t duration = 0;
uint8_t interval = 0;
uint16_t frequency = 0;
uint8_t type = 0;
uint32_t start_datetime = 0;
uint32_t timestamp = 0;

bool SLEEP_ACTIVE = false;

int current_power_src = -1; // Can be -1 = No valid input, 1 = batt1, 2 = batt2
const char* power_log_filename = "syslog.txt"; // Filename for logging power inputs
File log_file;

bool log_file_start = false;
int log_file_counter = 0; 
int log_file_counter_interval = 20; // Only log data every 20 iterations of main loop (~10sec)

File transferFile;
volatile uint32_t fileSize;
bool sdReady    = false;
volatile bool eofReached = false;
volatile bool file_transfer_active = false;
volatile bool requestBusy = false;
volatile bool reopenPending = false;

// ---------------------------------------

// Sensors ---------------------------------------------------------------------------------

TMP117 temp_sensor; // Initalize sensor

#define AL_ADDR 0x10

SparkFun_Ambient_Light veml_6030 = SparkFun_Ambient_Light(AL_ADDR);
// Possible values: .125, .25, 1, 2
// Both .125 and .25 should be used in most cases except darker rooms.
// A gain of 2 should only be used if the sensor will be covered by a dark
// glass.
float gain = .125;
// Possible integration times in milliseconds: 800, 400, 200, 100, 50, 25
// Higher times give higher resolutions and should be used in darker light. 
int integtime = 100;

void init_light_sensor(void){
  veml_6030.begin();
  // Again the gain and integration times determine the resolution of the lux
  // value, and give different ranges of possible light readings. Check out
  // hoookup guide for more info. 
  veml_6030.setGain(gain);
  veml_6030.setIntegTime(integtime);

  printf("Reading settings...\n"); 
  float gainVal = veml_6030.readGain();
  printf("Gain: %ld", (long)(gainVal));
  int timeVal = veml_6030.readIntegTime();
  printf(" Integration Time: %ld\n", (long)(timeVal));
}

void init_temp_sensor(void){
  temp_sensor.begin(0x49);
}

long read_light_lux(void){
  light_lux = veml_6030.readLight(); 
  return light_lux;
}

float read_temp(void){
  if (temp_sensor.dataReady() == true) // Function to make sure that there is data ready to be printed, only prints temperature values when data is ready
  {
    temp_celsius = temp_sensor.readTempC();  
  }  
  return temp_celsius;
}
// ---------------------------------------------------------------------------------------

// GPIO ------------------------------------------------------------------------------------

void configureGPIO(void){
    /*  INPUTS
    --------------*/ 
    pinMode(TURN_ON_OFF, INPUT);
    pinMode(RPI_GPIO22, INPUT);
    pinMode(BATT_ST, INPUT);

    /*  OUTPUTS
    --------------*/ 
    pinMode(LED_BUILTIN, OUTPUT);digitalWrite(LED_BUILTIN, LOW);  // Led Pin
    pinMode(BATT1_LED, OUTPUT);digitalWrite(BATT1_LED, LOW);  // BATT1 Led Pin
    pinMode(BATT2_LED, OUTPUT);digitalWrite(BATT2_LED, LOW);  // BATT2 Led Pin

    pinMode(EN_5V, OUTPUT);digitalWrite(EN_5V, LOW);  // System Power off
    pinMode(EN_10V, OUTPUT);digitalWrite(EN_10V, LOW);  // LED 14V boost off
    pinMode(BATT_SW, OUTPUT);digitalWrite(BATT_SW, LOW); // BATT1 = low, BATT2 = high

}
// ---------------------------------------------------------------------------------------

// Lights ----------------------------------------------------------------------------------

Adafruit_DS3502 ds3502 = Adafruit_DS3502();

void init_lights(void){
  if (!ds3502.begin(0x28)){
    ds3502.begin(0x2B);
  }
}

void lights_on(uint8_t brightness) {
  digitalWrite(EN_10V, HIGH);
  delay(5);

  // Set wiper 
  uint8_t wiper_lvl = (brightness * 127) / 100; // Adjust brightness (0-100) to wiper range (0-127)
  ds3502.setWiper(wiper_lvl);
}

void lights_off(void) {
  // Turn off 14v boost
  digitalWrite(EN_10V, LOW);
  delay(5);
}

// ---------------------------------------------------------------------------------------


// RTC ------------------------------------------------------------------------------------

STM32RTC& rtc = STM32RTC::getInstance();

void init_rtc(){
  // Select RTC clock source: LSI_CLOCK, LSE_CLOCK or HSE_CLOCK.
  // By default the LSI is selected as source.
  rtc.setClockSource(STM32RTC::LSE_CLOCK);

  rtc.begin();   // the function to get the time from the RTC

  if (!rtc.isTimeSet()) {
    struct tm t;
    memset(&t, 0, sizeof(t));

    // Parse time: "hh:mm:ss"
    t.tm_hour = atoi(__TIME__);
    t.tm_min  = atoi(__TIME__ + 3);
    t.tm_sec  = atoi(__TIME__ + 6);

    // Parse date: "Mmm dd yyyy"
    char monthStr[4];
    int day, year;
    sscanf(__DATE__, "%s %d %d", monthStr, &day, &year);
    t.tm_mday = day;
    t.tm_year = year - 1900; // tm_year is years since 1900

    const char* months[] = {
      "Jan", "Feb", "Mar", "Apr", "May", "Jun",
      "Jul", "Aug", "Sep", "Oct", "Nov", "Dec"
    };
    for (int i = 0; i < 12; ++i) {
      if (strncmp(monthStr, months[i], 3) == 0) {
      t.tm_mon = i; // tm_mon is 0-based
      break;
      }
    }

    rtc.setEpoch(mktime(&t));
  }

}

void read_rtc(){
  timestamp = rtc.getEpoch();
}
// ---------------------------------------------------------------------------------------

// RPi I2C ---------------------------------------------------------------------------------

#define I2C_ADDRESS 0x24

/*
# I2C register map:
# 
# Reg  | Type | Name                | Function                          | Number of Bytes
# ---- | ---- | ----                | ----                              | ----
# 0x01 | R    | RTC                 | RTC time data (Unix timestamp)    | 4 Bytes (32 bits) sent top byte to low byte in order 
# 0x02 | R    | RPi Volts           | --                                | 2 Byte (16 bits signed)  
# 0x03 | R    | RPi Current         | --                                | 2 Byte (16 bits signed)
# 0x04 | R    | RPi Power           | --                                | 2 Byte (16 bits signed)
# 0x05 | R    | uC Volts            | --                                | 2 Byte (16 bits signed)
# 0x06 | R    | uC Current          | --                                | 2 Byte (16 bits signed)
# 0x07 | R    | uC Power            | --                                | 2 Byte (16 bits signed)
# 0x08 | R    | Batt Volts          | --                                | 2 Byte (16 bits signed)
# 0x09 | R    | Batt Current        | --                                | 2 Byte (16 bits signed)
# 0x10 | R    | Batt Power          | --                                | 2 Byte (16 bits signed)
# 0x11 | W    | Acq config OUT      | Experimental configuration times  | 5 Bytes, duration (8 bits), interval (8 bits), frequency (16 bits), type (8 bits) 
# 0x12 | R    | Acq config IN       | Experimental configuration times  | 5 Bytes, duration (8 bits), interval (8 bits), frequency (16 bits), type (8 bits) 
# 0x13 | W    | Watchdog timer      | Time before power on RPi (mins)   | 2 Bytes (16 bits)
# 0x14 | R    | Poweroff timer      | Timer before power off RPi (secs) | 2 Bytes (16 bits)
*/

// Register definitions
#define REG_TIMESTAMP 0x01

#define REG_RPI_VOLTS 0x02
#define REG_RPI_CURRENT 0x03
#define REG_RPI_POWER 0x04

#define REG_UC_VOLTS 0x05
#define REG_UC_CURRENT 0x06
#define REG_UC_POWER 0x07

#define REG_BATT1_VOLTS 0x08
#define REG_BATT1_CURRENT 0x09
#define REG_BATT1_POWER 0x10

#define REG_BATT2_VOLTS 0x11
#define REG_BATT2_CURRENT 0x12
#define REG_BATT2_POWER 0x13

#define REG_ACQ_CONFIG_R 0x14
#define REG_ACQ_CONFIG_W 0x15

#define REG_WATCHDOG 0x16
#define REG_POWEROFF 0x17

#define REG_WTEMP 0x18
#define REG_WLIGHT 0x19

#define REG_DT_ADJUST 0x20

#define REG_LED_BRIGHTNESS 0x21

#define REG_LOG_TRANSFER 0x22
#define CHUNK_SIZE 32

volatile uint8_t register_address;
volatile bool is_register_address_received = false;

TwoWire Wire2(SDA2_SLAVE, SCL2_SLAVE);

// Functions for handling receive events ---------------------------

void reopenFile() {
  if (transferFile) transferFile.close();
  transferFile = SD.open(power_log_filename, FILE_READ);
  eofReached = false;

  fileSize = transferFile ? transferFile.size() : 0;

  if (transferFile) {
    file_transfer_active = true;
    printf("Successfully opened log file for transfer.");
  } else {
    printf("Unable to open log file for transfer.");
  }
}

void get_acq_config() {
  // Retrieve acquisition config from RPi
  // These variables are currently unused by the teensy but may be at a future date
  int bts = Wire2.available();
  if (bts < 5) return; // Incomplete config

  duration = Wire2.read();
  interval = (Wire2.read() << 8) | (Wire2.read() & 0xff);
  frequency = (Wire2.read() << 8) | (Wire2.read() & 0xff);
  type = Wire2.read();
  start_datetime = (Wire2.read() << 24) | (Wire2.read() << 16) | (Wire2.read() << 8) | (Wire2.read() & 0xff);    
}

void receive_event(int howMany) {
  if (howMany < 1) return; // Ignore empty transmissions

  while (Wire2.available()) {
    register_address = Wire2.read(); // Read the register address
    is_register_address_received = true;

    // Trigger different ISRs depending on the received address
    if (howMany > 1) {
      if (register_address == REG_ACQ_CONFIG_W) { 
        get_acq_config();
      } else if (register_address == REG_WATCHDOG){
        watchdog_time_config = (Wire2.read() << 24) | (Wire2.read() << 16) | (Wire2.read() << 8) | (Wire2.read() & 0xff);
      } else if (register_address == REG_POWEROFF){
        poweroff_time_config = (Wire2.read() << 8) | (Wire2.read() & 0xff);
      } else if (register_address == REG_DT_ADJUST) {
        uint32_t dt_adjust = (Wire2.read() << 24) | (Wire2.read() << 16) | (Wire2.read() << 8) | (Wire2.read() & 0xff);
        rtc.setEpoch(dt_adjust);
      } else if (register_address == REG_LED_BRIGHTNESS) {
        led_brightness = Wire2.read();
        printf("Received wiper brightness: %lu \n", led_brightness);
      } else if (register_address == REG_LOG_TRANSFER){
        uint8_t cmd = Wire2.read();
        if (cmd == 0x00) {
          reopenPending = true;
        }
      }
    }
  }
}

void send_uint_32bit(uint32_t data){
  Wire2.write((uint8_t)(data >> 24));
  Wire2.write((uint8_t)(data >> 16));
  Wire2.write((uint8_t)(data >> 8));
  Wire2.write((uint8_t)data);
}

// Functions for handling request events
void send_acq_config() {
  Wire2.write((uint8_t)duration); 
  Wire2.write((uint8_t)(interval >> 8)); 
  Wire2.write((uint8_t)(interval)); 
  Wire2.write((uint8_t)(frequency >> 8)); 
  Wire2.write((uint8_t)(frequency)); 
  Wire2.write((uint8_t)type);   
  send_uint_32bit(start_datetime);
}

void send_rtc() {
  send_uint_32bit(timestamp);
}

// Converts float to int, only works for 2 decimal places.
void send_float(float value) {
  int value_int = value * 100;
  Wire2.write((uint8_t)(value_int >> 8)); 
  Wire2.write((uint8_t)(value_int)); 
}

void transfer_request() {
  if (requestBusy) {
    uint8_t busy[CHUNK_SIZE];
    memset(busy, 0, CHUNK_SIZE);
    busy[0] = 0xFD; // busy marker
    Wire2.write(busy, CHUNK_SIZE);
    return;
  }
  requestBusy = true;

  uint8_t buffer[CHUNK_SIZE];
  memset(buffer, 0, CHUNK_SIZE);

  if (!sdReady) {
    buffer[0] = 0xFB;
    Wire2.write(buffer, CHUNK_SIZE);
    requestBusy = false;
    return;
  }

  if (!transferFile) {
    buffer[0] = 0xFC; // error marker (bad file handle)
    Wire2.write(buffer, CHUNK_SIZE);
    requestBusy = false;
    return;
  }

  if (eofReached) {
    buffer[0] = 0xFF;
    Wire2.write(buffer, CHUNK_SIZE);
    requestBusy = false;
    file_transfer_active = false;
    return;
  }

  uint32_t filePos  = transferFile.position();

  if (fileSize == 0 || filePos >= fileSize) {
    buffer[0] = 0xFF; // genuine EOF marker
    Wire2.write(buffer, CHUNK_SIZE);
    eofReached  = true;
    requestBusy = false;
    file_transfer_active = false;
    return;
  }

  size_t bytesToSend = transferFile.read(&buffer[1], CHUNK_SIZE - 1);

  if (bytesToSend == 0) {
    buffer[0] = 0xFD; // error marker (read failed)
    Wire2.write(buffer, CHUNK_SIZE);
    requestBusy = false;
    return;
  }

  buffer[0] = (uint8_t)bytesToSend;
  Wire2.write(buffer, CHUNK_SIZE);

  requestBusy = false;
}

// Function to handle outgoing data (to master)
void request_event() {
  if (!is_register_address_received) return; // No register address received

  switch (register_address) {
    case REG_LOG_TRANSFER:
      transfer_request();
      break;
    case REG_RPI_VOLTS:
      send_float(rpi_volts);
      break;
    case REG_RPI_CURRENT:
      send_float(rpi_current);
      break;
    case REG_RPI_POWER:
      send_float(rpi_power);
      break;
    case REG_UC_VOLTS:
      send_float(uc_volts);
      break;
    case REG_UC_CURRENT:
      send_float(uc_current);
      break;
    case REG_UC_POWER:
      send_float(uc_power);
      break;
    case REG_BATT1_VOLTS:
      send_float(batt1_volts);
      break;
    case REG_BATT1_CURRENT:
      send_float(batt1_current);
      break;
    case REG_BATT1_POWER:
      send_float(batt1_power);
      break;
    case REG_BATT2_VOLTS:
      send_float(batt2_volts);
      break;
    case REG_BATT2_CURRENT:
      send_float(batt2_current);
      break;
    case REG_BATT2_POWER:
      send_float(batt2_power);
      break;
    case REG_TIMESTAMP:
      send_rtc();
      break;    
    case REG_ACQ_CONFIG_R:
      send_acq_config();
      break;    
    case REG_WATCHDOG:      
      send_uint_32bit(watchdog_time_config);
        break;
    case REG_POWEROFF:      
        Wire2.write((uint8_t)(poweroff_time_config >> 8)); 
        Wire2.write((uint8_t)(poweroff_time_config));
        break;
    case REG_WTEMP:
      send_float(temp_celsius);
      break;
    case REG_WLIGHT:
      send_float(light_lux);
      break;    
  }
  is_register_address_received = false; // Reset for the next transaction
}

void configure_i2c(void) {
  // Initialize Wire2 (SDA2, SCL2)
  Wire2.begin(I2C_ADDRESS);
  Wire2.onReceive(receive_event);
  Wire2.onRequest(request_event);
}
// ---------------------------------------------------------------------------------------

// Power monitoring ----------------------------------------------------------------------

Adafruit_INA260 ina260_5v = Adafruit_INA260();
Adafruit_INA260 ina260_3v3 = Adafruit_INA260();
Adafruit_INA260 ina260_batt1 = Adafruit_INA260();
Adafruit_INA260 ina260_batt2 = Adafruit_INA260(); // Current unused

void init_power_mon(){
  ina260_3v3.begin(0x41);
  ina260_5v.begin(0x40);
  ina260_batt1.begin(0x45);
  ina260_batt2.begin(0x44);
}

void read_batt_volts(){
    ina260_batt1.setMode(INA260_MODE_CONTINUOUS);
    ina260_batt2.setMode(INA260_MODE_CONTINUOUS);
    delay(5);
    
    batt1_volts = ina260_batt1.readBusVoltage()/1000;
    batt2_volts = ina260_batt2.readBusVoltage()/1000;

    ina260_batt1.setMode(INA260_MODE_SHUTDOWN);
    ina260_batt2.setMode(INA260_MODE_SHUTDOWN);
    delay(5);
}

void read_power(){
    // Initiate before read
    ina260_batt1.setMode(INA260_MODE_CONTINUOUS);
    ina260_batt2.setMode(INA260_MODE_CONTINUOUS);
    ina260_3v3.setMode(INA260_MODE_CONTINUOUS);
    ina260_5v.setMode(INA260_MODE_CONTINUOUS);
    delay(5);

    rpi_current = ina260_5v.readCurrent()/1000;
    rpi_volts = ina260_5v.readBusVoltage()/1000;
    rpi_power = ina260_5v.readPower()/1000;

    uc_current = ina260_3v3.readCurrent()/1000;
    uc_volts = ina260_3v3.readBusVoltage()/1000;
    uc_power = ina260_3v3.readPower()/1000;

    batt1_current = ina260_batt1.readCurrent()/1000;
    batt1_volts = ina260_batt1.readBusVoltage()/1000;
    batt1_power = ina260_batt1.readPower()/1000;

    batt2_current = ina260_batt2.readCurrent()/1000;
    batt2_volts = ina260_batt2.readBusVoltage()/1000;
    batt2_power = ina260_batt2.readPower()/1000;

    // Shutdown when not in use
    ina260_batt1.setMode(INA260_MODE_SHUTDOWN);
    ina260_batt2.setMode(INA260_MODE_SHUTDOWN);
    ina260_3v3.setMode(INA260_MODE_SHUTDOWN);
    ina260_5v.setMode(INA260_MODE_SHUTDOWN);    
    delay(5);
}

// ---------------------------------------------------------------------------------------

// Main code -----------------------------------------------------------------------------

bool POWER_ON = false; // true if NTURN_ON received, false if NTURN_OFF received
bool RPI_POWER_ON = false;
int SWITCH_COUNT = 0;

extern "C" int _write(int file, char *ptr, int len) {
  // Send characters over SWO (ITM Port 0)
  for (int i = 0; i < len; i++) {
    ITM_SendChar(*ptr++);
  }
  return len;
}

void flash_led_builtin(int duration){
  digitalWrite(LED_BUILTIN, HIGH);
  delay(duration);
  digitalWrite(LED_BUILTIN, LOW);
}
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
void loop() {
  // Update readouts
  read_power();
  read_rtc();
  read_light_lux();
  read_temp();

  POWER_CHECK = check_and_switch_power();

  printf("Timestamp: %lu, Watchdog time: %lu, Poweroff time: %lu\n", 
         timestamp, watchdog_end_time, poweroff_end_time);

  printf("ON/OFF switch state: %d, RPI POWER ON: %d, Charge check: %d\n", 
         digitalRead(TURN_ON_OFF), RPI_POWER_ON, POWER_CHECK);

  printf("Batt1: %ld mV, Batt2: %ld mV\n",
        (long)(batt1_volts * 1000.0f),
        (long)(batt2_volts * 1000.0f));

  if (reopenPending && !requestBusy) {
      reopenPending = false;
      reopenFile();
  }

  if (eofReached && transferFile) {
      transferFile.close();
      file_transfer_active = false;
  }

  // If a watchdog timer has been received from RPi
  if ((watchdog_time_config > 0) && (watchdog_end_time == 0)) {
      watchdog_end_time = watchdog_time_config;
  } else if ((watchdog_time_config == 0) && (watchdog_end_time != 0)) {
      watchdog_end_time = 0;
  }

  // If a power-off timer has been received from RPi
  if ((poweroff_time_config > 0) && (poweroff_end_time == 0)) {
      poweroff_end_time = timestamp + poweroff_time_config;
  } else if ((poweroff_time_config == 0) && (poweroff_end_time != 0)) {
      poweroff_end_time = 0;
  }

  // Somewhat janky periodic check to turn on/off external LEDs
  // Would be better as an interrupt
  if (digitalRead(RPI_GPIO22) == HIGH) {
    lights_on(led_brightness);  
  } else {
    lights_off();
  }

  // If watchdog timer has finished, power on RPi
  if ((timestamp >= watchdog_end_time) && (watchdog_end_time > 0)) {
    if (POWER_CHECK) {
      printf("Turning RPI on...");        
      digitalWrite(EN_5V, HIGH);
      RPI_POWER_ON = true;
    }
    watchdog_time_config = 0;
    watchdog_end_time = 0;
  }

  // If power-off timer has passed, power off RPi
  if ((timestamp >= poweroff_end_time) && (poweroff_end_time > 0)) {
      printf("Turning RPI off...");        
      digitalWrite(EN_5V, LOW);
      RPI_POWER_ON = false;
      poweroff_time_config = 0;
      poweroff_end_time = 0;
  }

  if (file_transfer_active == false) {
    if (log_file_start == false) {
      log_power();
      log_file_start = true;
    }

    if (log_file_counter == log_file_counter_interval) {
      log_power();
      log_file_counter = 0;
    }

    log_file_counter += 1;
  }

  if (POWER_ON == true) {
    int on_off_switch_state = digitalRead(TURN_ON_OFF);

    if (on_off_switch_state == HIGH) {
      SWITCH_COUNT = SWITCH_COUNT + 1;
    } else {
      SWITCH_COUNT = 0; // If switch not active, reset counter
    }
  }

  if (SWITCH_COUNT > 5) {
    turn_off();
    SWITCH_COUNT = 0;
  }

  // Power down to prevent over discharge
  if (POWER_CHECK == false){
    turn_off();
  }
  
  // flash_led_builtin(50);
  // delay(1000);

  // Check which batt is being used and flash corresponding led
  int batt_stat = digitalRead(BATT_ST);
  if (batt_stat == HIGH){
    digitalWrite(BATT2_LED, HIGH);
    delay(50);
    digitalWrite(BATT2_LED, LOW);
  } else {
    digitalWrite(BATT1_LED, HIGH);
    delay(50);
    digitalWrite(BATT1_LED, LOW);
  }


  if (RPI_POWER_ON == false) {
    SLEEP_ACTIVE = true;
    flash_led_builtin(50);
    // delay(1000);
    LowPower.deepSleep(10000);
  } else {
    flash_led_builtin(50);
    delay(1000);
  }
}

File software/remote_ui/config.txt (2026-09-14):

# For more options and information see
# http://rptl.io/configtxt
# Some settings may impact device functionality. See link above for details

# Uncomment some or all of these to enable the optional hardware interfaces
dtparam=i2c_arm=on
#dtparam=i2s=on
#dtparam=spi=on

# Enable audio (loads snd_bcm2835)
dtparam=audio=on

# Additional overlays and parameters are documented
# /boot/firmware/overlays/README

# Automatically load overlays for detected cameras
camera_auto_detect=1

# Automatically load overlays for detected DSI displays
display_auto_detect=1

# Automatically load initramfs files, if found
auto_initramfs=1

# Enable DRM VC4 V3D driver
dtoverlay=vc4-kms-v3d
max_framebuffers=2

# Don't have the firmware create an initial video= setting in cmdline.txt.
# Use the kernel's default instead.
disable_fw_kms_setup=1

# Run in 64-bit mode
arm_64bit=1

# Disable compensation for displays with overscan
disable_overscan=1

# Run as fast as firmware / board allows
arm_boost=0

[cm4]
# Enable host mode on the 2711 built-in XHCI USB controller.
# This line should be removed if the legacy DWC2 controller is required
# (e.g. for USB device mode) or if USB support is not required.
otg_mode=1

[cm5]
dtoverlay=dwc2,dr_mode=host

[all]
enable_tvout=0
dtoverlay=disable-bt

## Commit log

2026-09-14 Initial commit.
    [1612898-1.SchLib, 1612898-1.stp, 16128981.PcbLib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]
2026-09-14 rename files.
    [fieldcam-B_Cu.gbr, fieldcam-B_Mask.gbr, fieldcam-B_Paste.gbr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]
2026-09-14 Update app code with latest bug fixes.
    [camera.py, deployment.py, fieldcam_v2_main.ino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]
